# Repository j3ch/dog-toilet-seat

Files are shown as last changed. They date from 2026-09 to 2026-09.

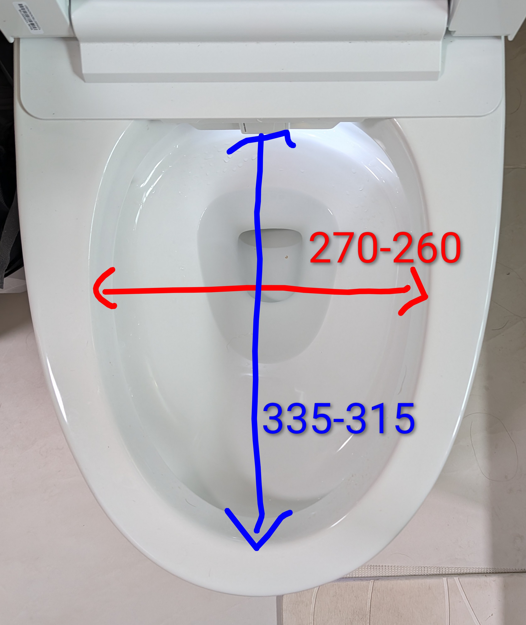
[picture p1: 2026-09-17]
measurements.jpg

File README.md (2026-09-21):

# toiletseat
Design files for a Toilet Seat for Lala for the Kohler Reve for when she gets too old to balance

Lala is getting old and may not be able to balance on the rim for much longer.  These files are for a 3d printed insert to increase the surface area that she can stand on. All four of my toilets are the Kohler Reve, which is square and does not accept standard toiletseats.



Lala primarily balances on the front rim, so that is the area which I intended to make larger.

A piece of clear film was placed over the toilet and it was traced with a marker.



I then replicated the outline in illustrator, and used a cricut to cut the shape from cardstock.  I checked the shape against the toilet, and then made modifications to get as close as I could to the shape. The hole is slightly egg shaped, and the walls tilt inwards at diferent angles.  They are more steep near the corners.

I then used the vector file to extrude the 3d model out in fusion 360 and generally model the object as desired.

It was cut into 4 to facilitate printing on printers will smaller print beds.



I used a phone scanner to scan the toilet into a mesh model which is pretty rough, and looked to see if it matched my model.





The seat was printed in polycarbonate.

InShot_20231030_141507858

Some dimension gaps were noted. 6mm width and 2.5mm height.



It was coated in Gorilla clear spray, and the top was coated with the white plasti dip
It was pretty smooth so it was painted with the black plasti dip with a brush, two coats, then sand was sprinkled all over it
It was then sprayed again with the white plastidip before it really got a chance to dry
InShot_20231030_141906600

InShot_20231030_141920419

Lala was confused by the seat, probably smells strongly of the paint, and it also feels weird and changes how her feet can be positioned. She usually leaves one pad hanging on the inside edge, probably to know where the ledge is. Pretending to go into her crate with food was enough to light a fire under her butt to get her to do what I asked instead of just standing there and alternate looking at the toilet and me.

Typically if she's disinterested in something, if I act like I want it, suddenly she wants it 100x more. The moment I don't want it anymore, she doesn't either. I guess dogs are not all that different than humans.

IMAGE ALT TEXT HERE (https://youtu.be/0RVw_okE6QU)

IMAGE ALT TEXT HERE (https://youtu.be/AzDsTydvyec)

IMAGE ALT TEXT HERE (https://youtu.be/IX3H9Qvbffo)

A new model was made, with ridges and a differently shaped hole.  The geometry of the center flange was also slightly adjusted.



It was printed in PETG this time.

InShot_20231114_142916448

The gaps were filled with waterproof epoxy putty and the entire model was sprayed with the gorilla clear spray. The bottom was then coated in the black plasti dip.  The top was then coated with clear paint on flex seal and sprinkled with fine sand.  As of 12 hours later, it's still tacky, so cure time might be much longer than the plasti dip.

InShot_20231114_142951156

It may take a few days before it's cured enough to coat with the white plasti dip spray.

It took about 30 hours to cure. I then coated it with white spray plasti-dip.

The plasti dip peels freely from the cured flex seal paint on. This could be a feature, or a problem. For now I think it's more of a problem. I think the gorilla + plasti dip paint on + sand + plasti dip spray is a better combo. It also cures faster, but I can't remove the flex seal reasonably, so maybe for next time.

IMAGE ALT TEXT HERE (https://youtu.be/RBduAb9LdPU)

I find the cured flex seal to feel slippery, which is the opposite of what I want, so besides waterproofing it provides no benefit, since all the others also waterproof. It also cures really slow. Unless you want a surface that plasti-dip can peel from for easy replacement, I don't think it's useful.

I peeled off as much of the flex seal as possible and recoated the top with black plasti dip paint on. I then sprinkled it with sand, and coated it with plasti dip white spray. It's very lumpy, since I was unable to get all of the flex seal off, but it has a pretty grippy surface.

Seems fine though, lala doesn't have a problem with it, besides it being a new seat which probably feels a bit different.

IMAGE ALT TEXT HERE (https://youtu.be/_8LVXEE4Dok)

The third print will be a similar model in PC again. This one has 5 connection pegs in the joints and the central flange is a tiny tiny bit bigger.

I plan to glue it with scigrip 16, then coat it in the gorilla clear spray first, then paint the top in plasti-dip clear paint on.  Depending on the grippiness, sand + plasti-dip spray is an option.

The printer I have now has a 200 x 200 mm bed, and the v4 quadrants need up to a
226 mm square, so v4 was re-split into 8 pieces instead of 4:
`toiletv4_sliced_in_8.stl`.

The four original cuts (at X=0 and Z=0, through the middle of each side) are
untouched. Each quadrant gets one new radial cut through its corner, at 45, 135,
225 and 315 degrees. Every piece now fits a 164-180 mm square and is 94.7 mm
tall.

| piece | smallest square bed |
|---|---|
| S0 | 169 mm |
| S1 | 171 mm |
| S2 | 170 mm |
| S3 | 164 mm |
| S4 | 165 mm |
| S5 | 179 mm |
| S6 | 180 mm |
| S7 | 169 mm |

The new joints reuse the v4 connector exactly: 3 round pegs down the skirt
(5 mm peg into a 6 mm hole, 6 mm long, 7 mm deep) and 2 flat tongues in the top
flange (4 x 35 mm tongue into a 5 x 36 mm slot), 0.5 mm clearance per side
throughout. Male and female alternate so every joint has one of each.

One difference worth knowing before printing: the diagonal cuts meet the ~10.5 mm
skirt obliquely, so the bore drifts slightly across the wall as it goes in and
the sockets there are left with 1.1-1.8 mm of wall, against 1.5-2.0 mm on the
original cuts. Still 3+ perimeters, but the skirt pegs on the new corner joints
are the thinnest-walled feature in the part.

The pieces are exported exploded 40 mm outward, the same way the v4 file is laid
out. `tools/split8.py` regenerates the file from `toiletv4_sliced.stl` and
`tools/check8.py` verifies it (watertightness, volume, every connector and its
clearance, bed fit, and that neighbouring pieces mate without interference).
Both need `numpy`, `trimesh`, `manifold3d`, `scipy`, `shapely`.

Note the Fusion `.f3d` files were not updated - the 8-way split was done on the
v4 mesh, so it is STL only.

## Ridges, rebuilt on v4

The ridged redesign only exists here as Fusion `.f3d` archives, and their
geometry is an Autodesk ShapeManager BREP (`ASM BinaryFile4tY`) that nothing
outside Fusion can read - there is no cached mesh in the archive either, so the
shapes cannot be recovered without the kernel that made them.

`toiletv5_rings.svg` is readable though. It is 64 closed curves, each a uniform
outward offset of the hole outline, spaced 7.086 px apart, the innermost sitting
two steps out from the hole. Registering the v4 sketch hole (`toiletcuts_v2.svg`,
617.74 x 690.63 px) against the v4 model's own hole (219.1 x 242.9 mm) gives
0.3532 mm/px, which puts that spacing at 2.503 mm - so the pattern was laid out
on a 2.5 mm offset step.

The v5 hole is a different shape from v4's, so rather than dropping the v5 curves
onto the wrong outline, `tools/ridges.py` rebuilds the same construction on v4's
own hole: concentric outward offsets at 2.5 mm, raised on alternating bands.
### The top is flattened first

v4's top is a shallow dish - it rises about 2.7 mm from the inner edge out to the
rim - so ridges laid on it are not coplanar and a piece will not sit flat on a
bed. `split8.py` fills that dish up to its own high point (y = 14.702) before
anything else, so nothing is cut away and the outer rim keeps its height. The
slab starts at y = 8.6, above the flange slots, and its footprint is read below
them so they do not punch holes in it; it is held 0.25 mm inside the outline,
because flush its wall lands exactly on the part's own wall and that coincident
pair comes apart in the ridge union. A 0.25 mm strip of the original rounded rim
survives at the very edge, and the chamfer at the hole is likewise untouched -
99.87% of the ridged area is flat to within 0.01 mm.

Flattening adds 209 cm3, taking the seat from 2123 to 2333 cm3 before ridges.

Flattening would also square off the rounded lip v4 had where the top meets the
hole - the edge Lala's paws sit against - so a **2 mm 45 degree break** is cut
back along it, as a staircase of 0.2 mm steps that the layer lines round off
anyway. A true quarter-round was tried first and is not usable: its profile ends
in 0.01-0.09 mm offsets from the hole wall, slivers that do not survive STL's
float32 and left one quadrant non-watertight on reload. The break removes
1601 mm3, against 1599 predicted from the 727 mm hole perimeter.

The inset is taken on the assembled seat, so it pulls the slab back from the
outer wall and the hole but not from the cut planes. Applied per quadrant it
also pulled each slab back from its own seams, leaving a 0.5 mm groove down all
four of them. A hairline one (<= 0.2 mm) remains; the bridges cover it
everywhere except the innermost 5 mm.

Ridges are 2.5 mm wide with 2.5 mm flats between them, stand 1.5 mm proud, and
start 5 mm out from the hole. The SVG draws 64 rings, which is 32 bands reaching
162.5 mm - enough for the v5 outline but not for v4, whose back corners are up
to 185 mm from the hole and were left flat for the last 20-23 mm. The band count
is taken from the geometry instead, which comes to 38 here. They are cut from a lifted copy of the part rather
than stamped on at a fixed height, so they follow the sloping top face exactly.
All of that is parameterised at the top of the script.

- `toiletv4_ridged.stl` - the whole seat, 2326.3 cm3, 96.2 mm tall
- `toiletv4_ridged_in_8.stl` - the same thing in the 8 printable pieces

The joints are untouched: the ridge stock is floored at y=8.6 mm, above the
8.5 mm flange slots and below the top face, and each piece's stock is clipped to
its own sector, so no ridge material crosses a cut plane. `tools/check8.py`
passes on the ridged split - all 8 pieces closed shells, every connector still
5/6 mm and 4x35 / 5x36 at 0.5 mm clearance, still 164-180 mm square.

Two things this is not. It is v4 with the v5 ridge pattern, not a reproduction of
the model that was actually printed in PETG - that one also changed the hole
shape and the centre flange, and those changes are locked in the `.f3d`. And
`toiletv4_ridged.stl` is built by reassembling the v4 quadrants, so it keeps the
0.5 mm clearance gap around each of the 20 connectors of the original joints as
internal voids (3.7 cm3). There is no un-sliced v4 in the repo to build it from.

### One file per piece

`pieces/toiletv4_ridged_S0.stl` ... `_S7.stl` are the 8 ridged pieces as separate
solids, ready to open in a slicer: converted to Z up, turned about the vertical
axis to their smallest square footprint, centred on the origin and sitting on
Z=0. `tools/export_pieces.py` regenerates them, and takes any of the split files
as an argument.

| piece | footprint mm | tall mm | volume cm3 |
|---|---|---|---|
| S0 | 166.8 x 168.7 | 79.2 | 237.0 |
| S1 | 171.0 x 169.6 | 79.6 | 289.7 |
| S2 | 170.0 x 170.6 | 79.6 | 291.3 |
| S3 | 162.1 x 163.6 | 79.2 | 219.1 |
| S4 | 165.5 x 164.6 | 79.3 | 255.3 |
| S5 | 179.6 x 178.7 | 79.6 | 327.2 |
| S6 | 179.1 x 180.5 | 79.6 | 327.8 |
| S7 | 168.7 x 169.1 | 79.3 | 258.0 |

They are exported **turned over**: ridged face down, skirt pointing up. Printed
the other way up the flange cantilevers 80 mm out above the thin bottom edge of
the skirt and wants support under all of it; this way there is nothing to
support. The turn is a 180 degree rotation, never a mirror - `export_pieces.py`
asserts the placement matrix has determinant +1, because mirroring would reverse
every peg and socket. Pass `--upright` for the other orientation.

`export_pieces.py` also levels each piece onto its best resting plane, scoring
candidate hull facets by what actually touches the bed rather than by how much
area faces it. Now that the top is flat this comes out at **0.00 degrees** - the
pieces already sit flat. `--no-level` skips it, `--upright` turns them back over.

### Bridges across the ridges

A flat top is not enough on its own. The first print still lifted, and the
first-layer footprint shows why: the concentric bands land on the bed as about
25 unconnected ribbons, 2.5 mm wide and up to 250 mm long, with nothing joining
them until 1.5 mm up. Each ribbon is free to curl at its ends. Nothing was out
of plane - all 13294 mm2 of ridge top sat at exactly z=0 - so trimming ridge
height would not have helped; it would have left the same 25 ribbons.

A 10 mm radial bar at each cut plane crosses every band and ties them into one
network, and sits on a seam rather than in the middle of a face. Bars go at all
eight seam angles, not just the four 4-piece borders: the outermost bands exist
only in the corners and never reach a 4-piece border, so with four bars
12373 mm2 was still loose in 56 pieces.

Closing it off is a plain **10 mm border** right round the outer edge, no ridges
in it, which catches the outer end of every arc and encloses the pattern. With
the bars and the border together, **every piece's first layer is a single
connected region - 100%, all twelve of them**, quadrants and eighths alike.
Contact is **17083-20265 mm2** on the quadrants and 7680-11289 mm2 on the
eighths, against 13294-15850 and 3547-5854 before any of this.

Bands on one side, bars and border on the other, extruded apart and merged as
solids. Merged in 2D first they make one polygon with 1200+ points and 56
holes, which the triangulator cannot close. The bars and border do have to be
unioned with each other first, since the spokes run into the ring.

## Fitting the measured bowl

`measurements.jpg` has the opening measured on the toilet: **335 mm** on the long
axis and **270 mm** across at the rim, tapering inward to **315 x 260** over the
first 60 mm of depth. The skirt may go no more than 70 mm into the bowl.

### Skirt shortened to 65.4 mm

v4's skirt is 80 mm. It cannot simply be cut at 70 mm, because the lowest
connector is not at the same height on every original mating face - the four
lowest sockets top out at −68.0, −67.0, −67.0 and −65.905 mm - and a cut at −70
bisects three of them. The deepest cut that leaves every joint feature whole is
0.5 mm above the highest, so `SKIRT_TRIM_Y = -65.4`, giving a **65.4 mm** skirt.
That is under the 70 mm limit with room to spare.

The four original joints lose their lowest peg to the trim and now carry 2 pegs
+ 2 tongues. The four new diagonal joints still carry 3 pegs + 2 tongues, placed
by `split8.py` at whatever heights leave the most wall - it now searches within
6 mm of each nominal height rather than using fixed ones, because the skirt
thins and drifts differently around the ring. Wall left around the new sockets is
1.22-1.69 mm, against v4's own 1.5-2.0 mm.

Overall the seat is now 375 x 427 mm in plan and 81.6 mm tall, pieces
164-180 mm square and 81.1-81.6 mm tall.

### Does it drop in?

Yes, with 4.5-9.5 mm a side everywhere. `skirt_vs_bowl.png` overlays the skirt on
the measured opening. Comparing extreme dimensions at each depth:

| depth | skirt W x L | opening W x L | clearance per side |
|---|---|---|---|
| 1 mm | 255.9 x 319.9 | 269.8 x 334.7 | +7.0 / +7.4 |
| 10 mm | 251.8 x 315.8 | 268.3 x 331.7 | +8.3 / +7.9 |
| 20 mm | 249.5 x 313.7 | 266.7 x 328.3 | +8.6 / +7.3 |
| 40 mm | 245.2 x 309.5 | 263.3 x 321.7 | +9.1 / +6.1 |
| 60 mm | 241.1 x 305.3 | 260.0 x 315.0 | +9.4 / +4.9 |
| 65.4 mm | 240.0 x 304.1 | 259.1 x 313.2 | +9.5 / +4.5 |

The tightest point is +4.5 mm a side, at the bottom of the skirt on the long
axis. Nothing interferes at any depth.

One caveat, as ever: these are extreme dimensions, not shapes, and two outlines
with compatible bounding boxes need not nest. Tested against a true ellipse of
the stated axes the skirt is still slightly proud - 0.2 to 2.6 mm, worst at the
rim, at one end of the long axis, where the traced shape is squarer than an
ellipse. Real bowls are fuller than ellipses, which is presumably why it was
traced that way, and a couple of millimetres is inside the tolerance of a tape
measure on porcelain. Tracing the opening on film, as the original was, would
settle it outright.

### Four pieces, on v4's own cuts

`4pieces/toiletv4_ridged_Q0.stl` ... `_Q3.stl` are the ridged seat split the way
v4 originally was - the planes X=0 and Z=0, carrying v4's own connectors, no new
joints made. The quadrants already are that split, so they only needed the
ridges adding, each clipped to its own 90 degree sector so no ridge material
crosses a cut plane. Volumes sum to 2208.8 cm3 against the whole seat's 2208.9,
which is the check that nothing was added or removed.

| piece | footprint mm | tall mm | volume cm3 | smallest square bed |
|---|---|---|---|---|
| Q0 | 197.7 x 226.6 | 80.2 | 527.8 | 226 mm |
| Q1 | 187.6 x 220.8 | 80.3 | 511.5 | 220 mm |
| Q2 | 192.5 x 214.3 | 80.3 | 583.6 | 213 mm |
| Q3 | 191.0 x 208.6 | 80.3 | 586.9 | 207 mm |

**These do not fit a 200 mm bed** - they need 207 to 226 mm square, which is the
reason the seat was re-split into 8 in the first place. The 8-piece set in
`pieces/` (164-180 mm square) is still there. Everything else about the four
pieces is sound: each is a single closed shell, every edge used twice, and each
joint reads back as 2 pegs + 2 tongues at 0.5 mm clearance.

`tools/check8.py` works on either split - it takes the piece count from the file.

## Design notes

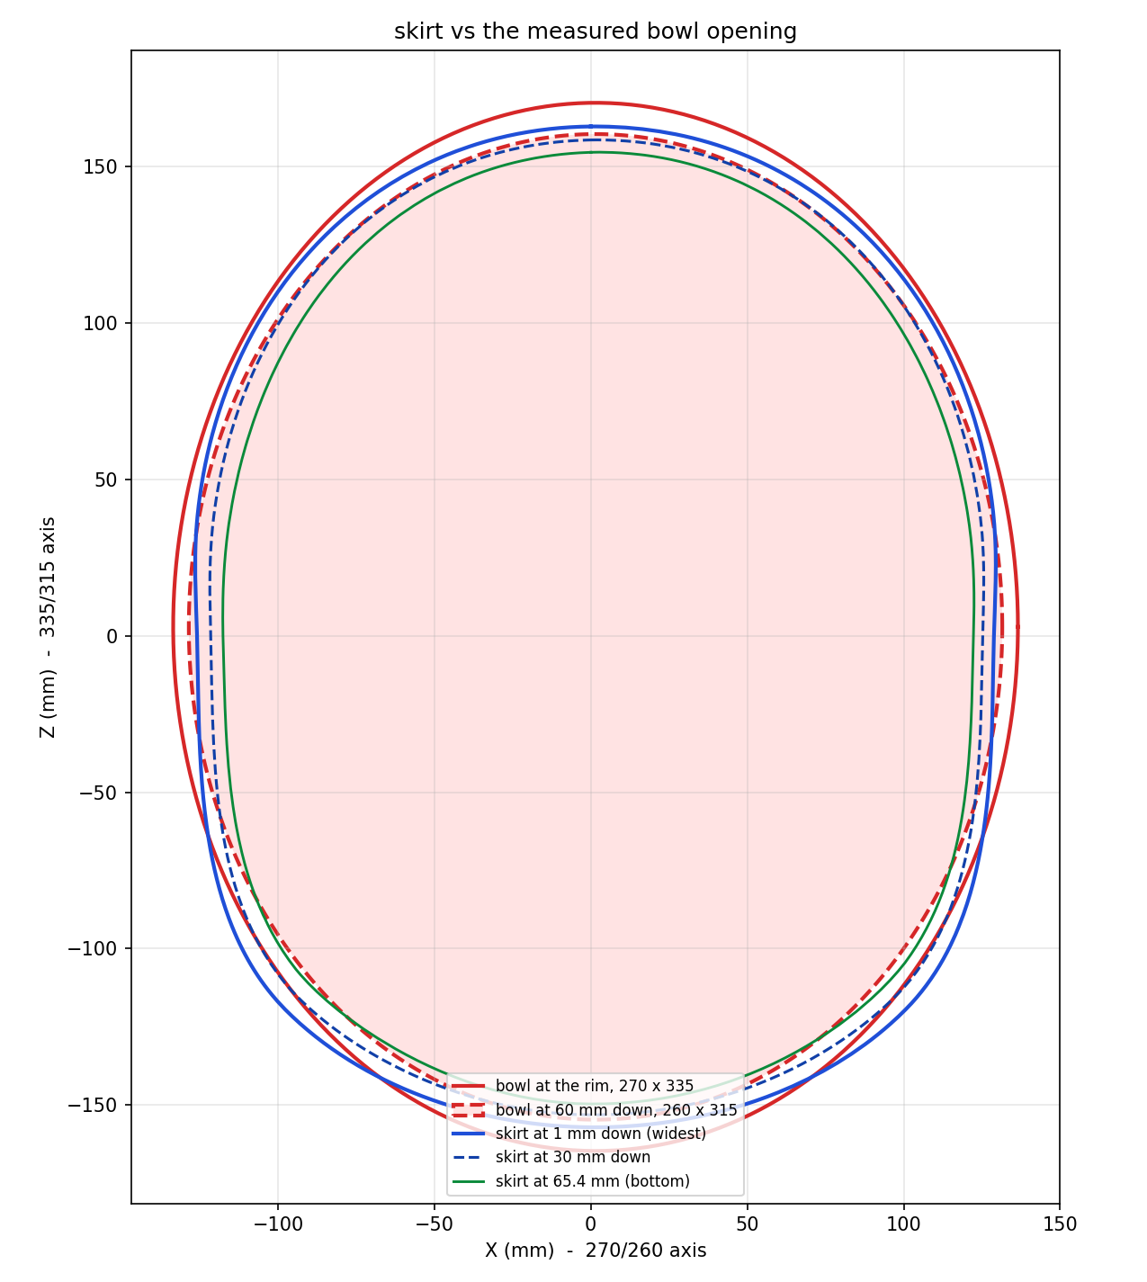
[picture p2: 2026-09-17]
skirt_vs_bowl.png

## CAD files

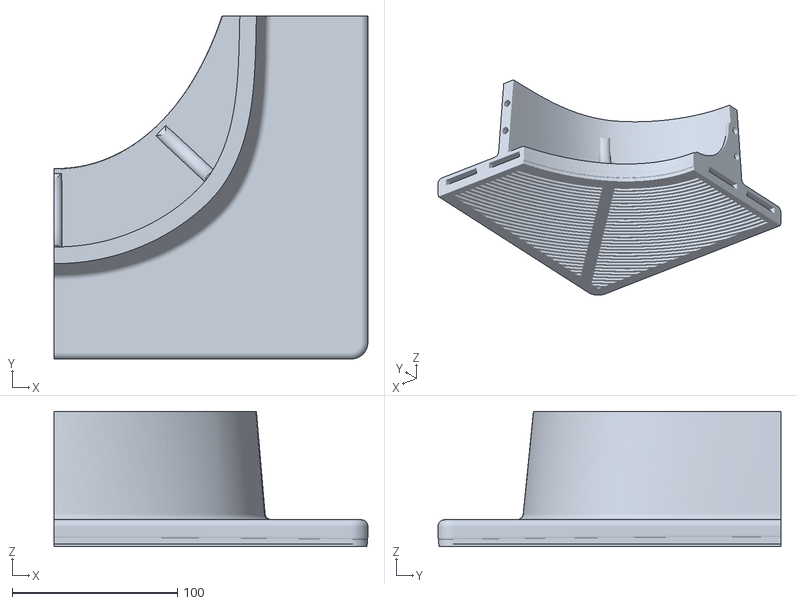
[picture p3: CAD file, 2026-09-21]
4pieces/toiletv4_ridged_Q3.stl
189.6 x 207.3 x 81.6

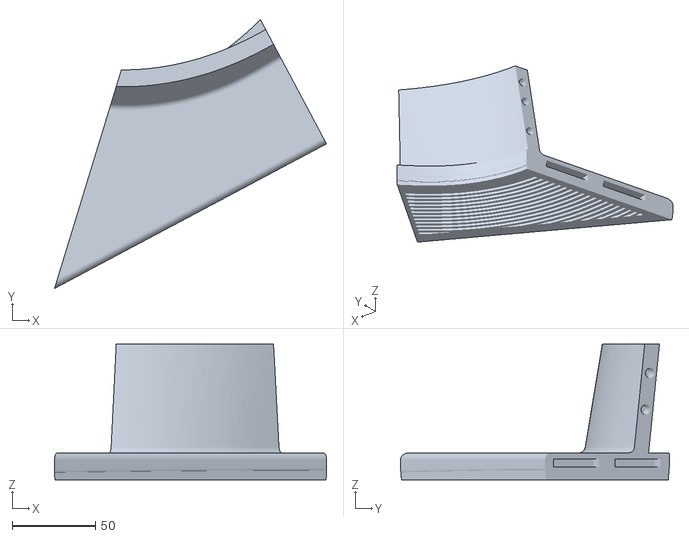
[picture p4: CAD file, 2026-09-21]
pieces/toiletv4_ridged_S3.stl
163.7 x 161.9 x 81.6

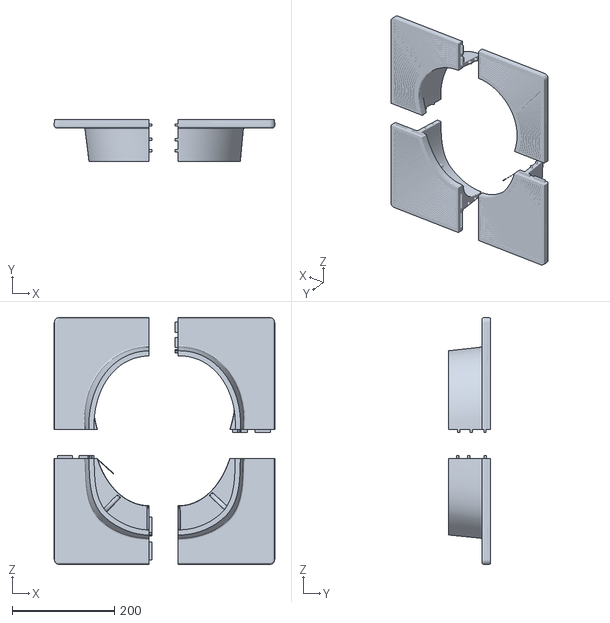
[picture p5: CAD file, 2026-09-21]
toiletv4_ridged_in_4.stl
431.6 x 81.6 x 483.4

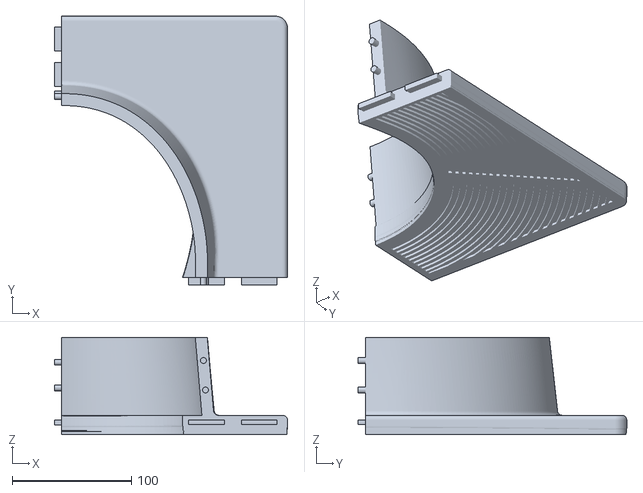
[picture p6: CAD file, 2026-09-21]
4pieces/toiletv4_ridged_Q0.stl
195.6 x 225.5 x 81.6

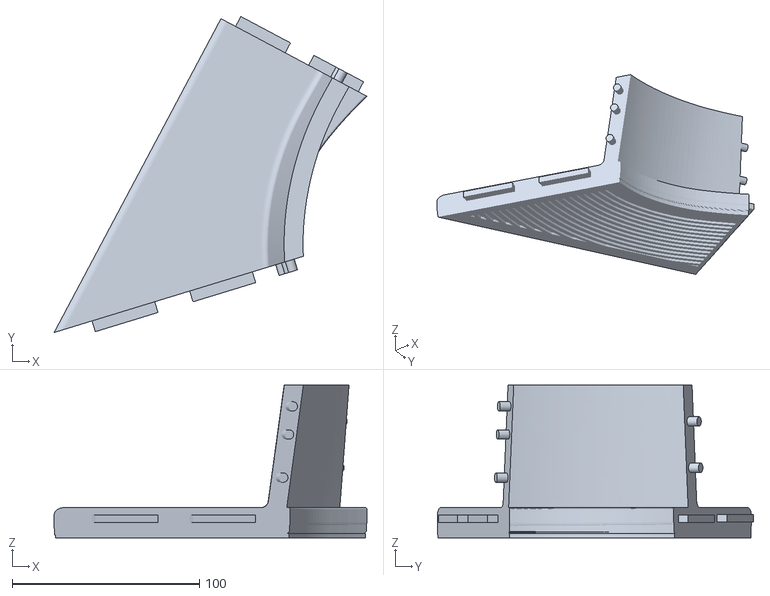
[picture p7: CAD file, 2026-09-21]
pieces/toiletv4_ridged_S0.stl
166.9 x 168.6 x 81.6

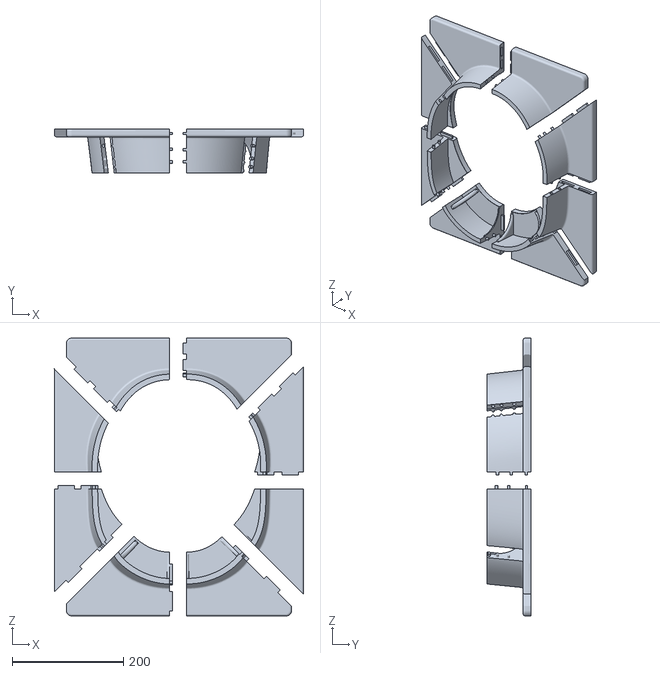
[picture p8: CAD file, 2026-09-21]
toiletv4_sliced_in_8.stl
448.9 x 80.1 x 500.7

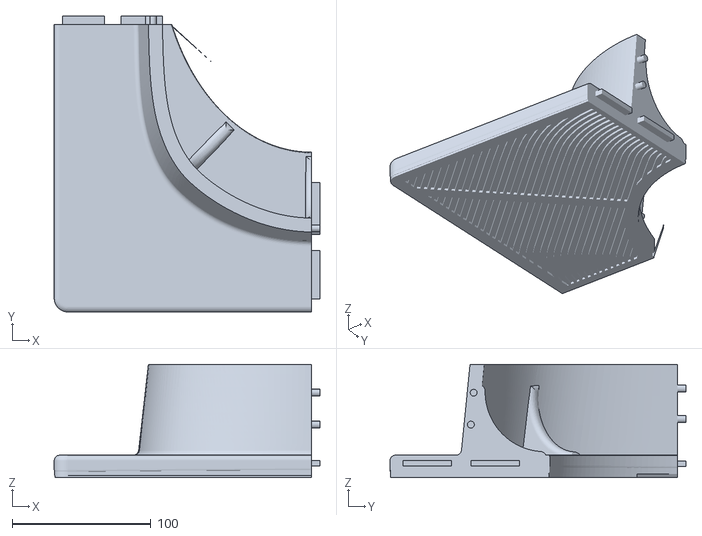
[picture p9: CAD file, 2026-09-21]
4pieces/toiletv4_ridged_Q2.stl
191.4 x 213.3 x 81.6

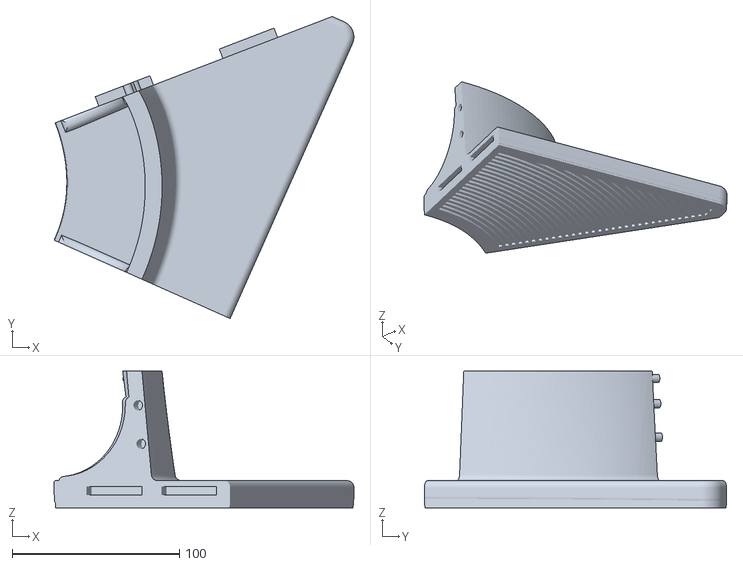
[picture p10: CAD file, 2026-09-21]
pieces/toiletv4_ridged_S6.stl
179.1 x 180.4 x 81.6

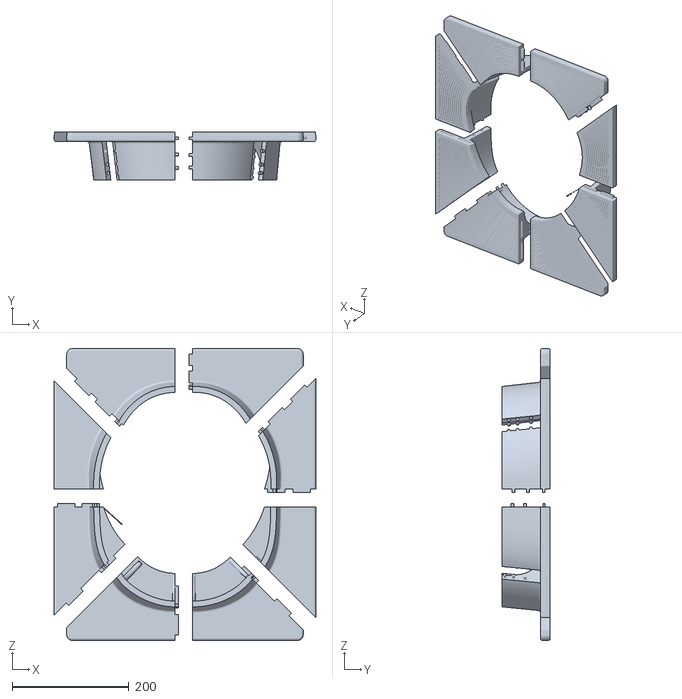
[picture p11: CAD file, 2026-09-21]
toiletv4_ridged_in_8.stl
448.9 x 81.6 x 500.7

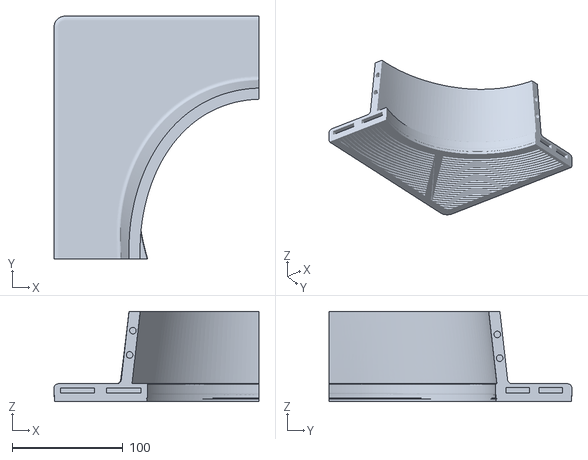
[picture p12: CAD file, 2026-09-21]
4pieces/toiletv4_ridged_Q1.stl
185.4 x 219.5 x 81.6

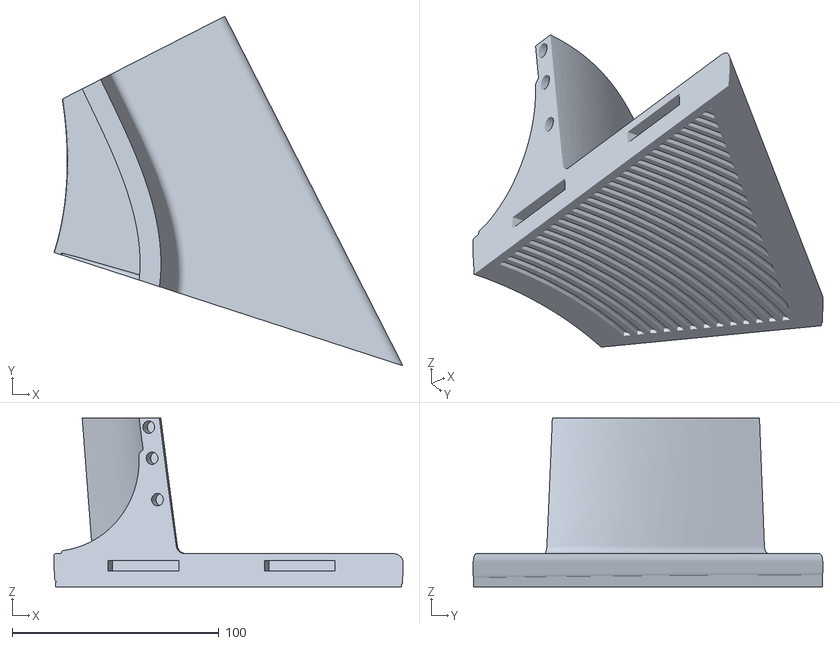
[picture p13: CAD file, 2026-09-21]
pieces/toiletv4_ridged_S7.stl
168.7 x 169.0 x 81.6

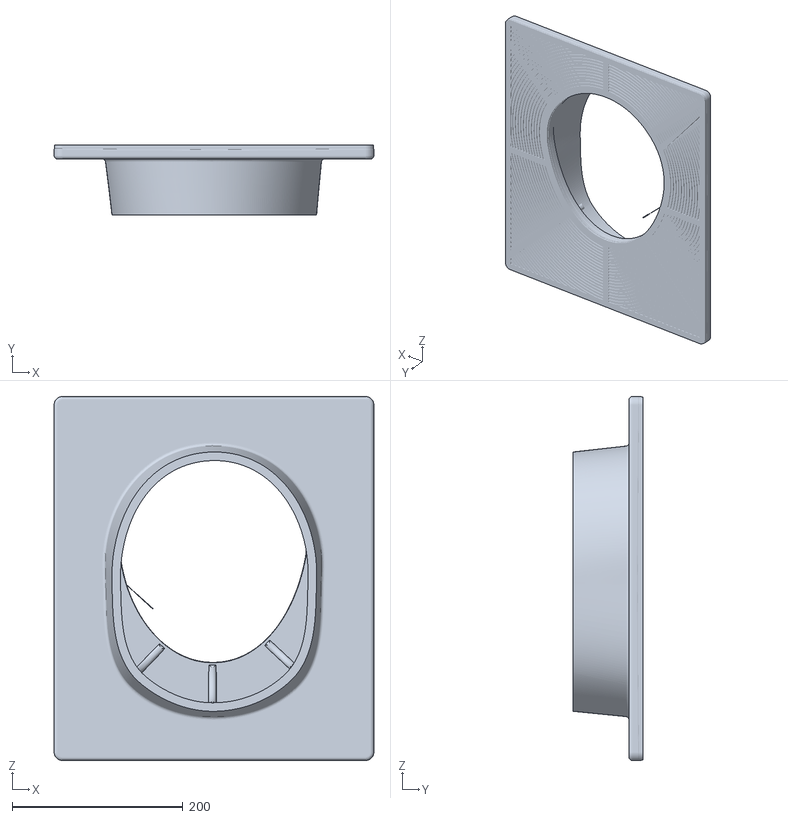
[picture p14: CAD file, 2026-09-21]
toiletv4_ridged.stl
375.0 x 81.6 x 426.8

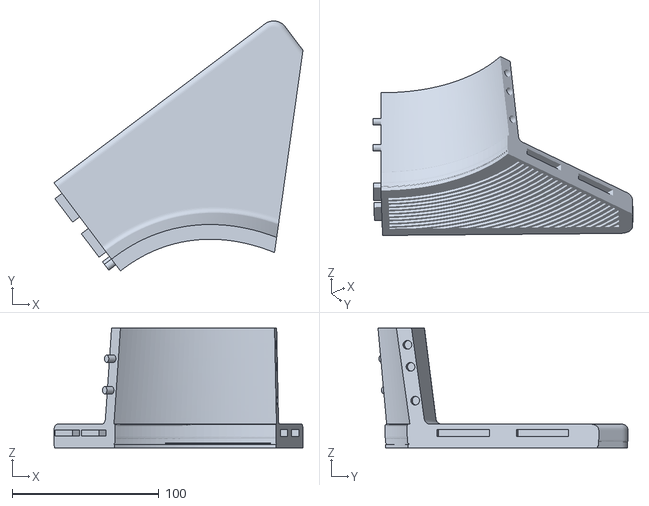
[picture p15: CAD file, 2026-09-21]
pieces/toiletv4_ridged_S1.stl
169.4 x 170.1 x 81.6

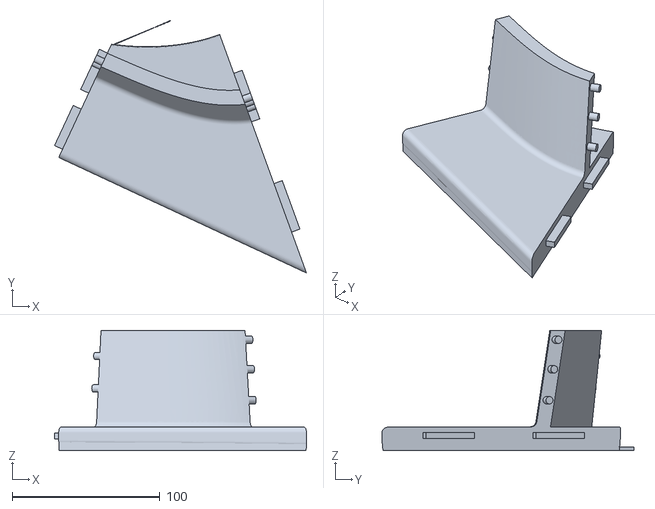
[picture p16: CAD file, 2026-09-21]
pieces/toiletv4_ridged_S4.stl
170.8 x 170.9 x 81.6

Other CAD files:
pieces/toiletv4_ridged_S5.stl
pieces/toiletv4_ridged_S2.stl

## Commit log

2026-09-16 Split v4 into 8 pieces to fit a 200 mm bed
    The v4 quadrants need up to a 226 mm square, which no longer fits. Add one
    radial cut through each quadrant's corner, at 45/135/225/315 degrees, leaving
    the four original cuts at X=0 and Z=0 untouched. Every piece now fits a
    164-180 mm square and is 94.7 mm tall.
    The new joints reuse the v4 connector exactly: 3 round pegs down the skirt
    (5 mm peg into a 6 mm hole) and 2 flat tongues in the flange (4x35 into 5x36),
    0.5 mm clearance per side, male and female alternating so every joint has one
    of each. Connector positions are measured from the cross-section at each cut
    rather than hard-coded, so each peg stays centred in its wall as the wall
    curves aw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
    [toiletv4_sliced_in_8.stl]
2026-09-16 Rebuild the ridged version on v4 geometry
    The ridged redesign is only in the .f3d archives, whose geometry is an Autodesk
    ShapeManager BREP with no cached tessellation, so it cannot be read outside
    Fusion. toiletv5_rings.svg can be read: 64 closed curves, each a uniform outward
    offset of the hole outline at 7.086 px, innermost two steps out.
    Registering the v4 sketch hole (toiletcuts_v2.svg, 617.74 x 690.63 px) against
    the v4 model's hole (219.1 x 242.9 mm) gives 0.3532 mm/px, putting that spacing
    at 2.503 mm - the pattern was laid out on a 2.5 mm offset step. The v5 hole is a
    different shape from v4's, so ridges.py rebuilds the construction on v4's own
    hole instead of mapping the v5 curves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
    [toiletv4_ridged.stl, toiletv4_ridged_in_8.stl]
2026-09-17 Export each ridged piece as its own STL
    The split files hold all 8 pieces in one mesh, in assembled-and-exploded
    positions with Y up, which a slicer reads as one object lying on its side.
    pieces/toiletv4_ridged_S0.stl ... _S7.stl are the same 8 solids one per file,
    converted to Z up, turned about the vertical axis to their smallest square
    footprint, centred on the origin and dropped onto Z=0.
    Each file verified independently of trimesh: single shell, every edge used
    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
    [toiletv4_ridged_S0.stl, toiletv4_ridged_S1.stl, toiletv4_ridged_S2.stl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]
2026-09-17 Trim the skirt to fit the measured bowl
    measurements.jpg gives the opening: 335 x 270 mm at the rim, tapering to
    315 x 260 about 10 mm down, with at most 70 mm of skirt allowed. v4's skirt is
    80 mm.
    It cannot just be cut at 70 mm. The lowest connector is at a different height on
    each original mating face - the four lowest sockets top out at -68.0, -67.0,
    -67.0 and -65.905 - so a cut at -70 bisects three of them, leaving half-pegs and
    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
    [toiletv4_ridged.stl, toiletv4_ridged_S0.stl, toiletv4_ridged_S1.stl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]
2026-09-17 Correct the bowl taper: 10 mm over 60 mm of depth
    I had read "tapers down 1cm" as the taper completing within 10 mm of the rim.
    It is 335 x 270 at the rim narrowing to 315 x 260 over the bowl's first 60 mm,
    so the opening is wider than assumed at every depth but the last.
    That removes the only interference. The skirt now clears by 4.5-9.5 mm a side
    everywhere, tightest at the bottom of the skirt on the long axis, instead of
    being 0.4 mm proud at 10 mm down. Against a true ellipse of the stated axes it
    is proud by 0.2-2.6 mm rather than 8.6 mm, small enough to sit inside both the
    tracing tolerance and the gap between an ellipse and a real bowl.
    No geometry change - the 65.4 mm skirt and the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
2026-09-20 Also split the ridged seat into 4 on v4's original cuts
    4pieces/toiletv4_ridged_Q0.stl ... _Q3.stl: the ridged seat cut the way v4 was,
    on X=0 and Z=0 with v4's own connectors. No new joints are made - the quadrants
    already are that split, so they only need the ridges adding, each clipped to its
    own 90 degree sector so no ridge material crosses a cut plane. The four volumes
    sum to 2208.8 cm3 against the whole seat's 2208.9, which is the check that the
    split neither adds nor removes anything.
    Each piece is a single closed shell with every edge used twice, and each joint
    reads back as 2 pegs + 2 tongues at 0.5 mm clearance.
    They do not fit a 200 mm bed: 207-226 mm square, which is why the se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
    [toiletv4_ridged_Q0.stl, toiletv4_ridged_Q1.stl, toiletv4_ridged_Q2.stl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]
2026-09-20 Export the pieces turned over, ridged face down
    Printed skirt-down the flange cantilevers 80 mm out above the thin bottom edge
    of the skirt and needs support under all of it. Turned over, the skirt points up
    and nothing needs support.
    The turn is a 180 degree rotation, not a mirror: export_pieces.py now asserts
    the placement matrix has determinant +1 and that the volume is unchanged, since
    mirroring would reverse every peg and socket and the pieces would no longer
    mate. --upright restores the old orientation.
    The ridged face does not quite lie flat - it is 0.5-1.3 degrees off parallel,
    which over a 170 mm piece is up to 3 mm against 1.5 mm ridges, so first-layer
    contact is 46-376 mm2 of ri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
    [toiletv4_ridged_Q0.stl, toiletv4_ridged_Q1.stl, toiletv4_ridged_Q2.stl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]
2026-09-20 Level each piece onto the bed instead of leaving it a degree proud
    Turned over, the ridged face points at the bed but sits about a degree off
    parallel - over a 170 mm piece that lifts one end clear of the 1.5 mm ridges, so
    only 46-376 mm2 was touching.
    export_pieces.py now shortlists the convex hull facets that point at the bed,
    lays each flat in turn, and keeps whichever actually puts the most material
    down. Scoring on real contact rather than on how much mesh area faces that way
    matters: the naive score left S6 resting on 1072 mm2 because a face can present
    plenty of area and still meet the bed along one edge.
    First-layer contact on the eight pieces goes from 46-376 mm2 to 3547-5854 mm2,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
    [toiletv4_ridged_Q0.stl, toiletv4_ridged_Q1.stl, toiletv4_ridged_Q2.stl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]
2026-09-20 Run the ridges out to every corner, not just 32 bands' worth
    The SVG draws 64 rings - 32 bands, reaching 162.5 mm from the hole. That covers
    the v5 outline, but v4's hole sits toward the front, so its back corners are
    183-185 mm out and the last 20-23 mm of Q2 and Q3 was left flat.
    The count now comes from the geometry: the furthest point of the flange from the
    hole, rounded up to a whole band, which is 38 here and reaches 192.5 mm. Q0 and
    Q1 were already covered and are byte-identical; Q2 and Q3 gain 0.4 and 0.5 cm3
    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
    [toiletv4_ridged.stl, toiletv4_ridged_Q0.stl, toiletv4_ridged_Q1.stl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]
2026-09-20 Flatten the seat's top, then re-split
    v4's top is a shallow dish rising ~2.7 mm from the inner edge to the rim, so
    ridges laid on it are not coplanar and no piece sits flat on a bed. split8.py
    now fills that dish up to its own high point (y = 14.702) before anything else,
    so nothing is cut away and the rim keeps its height. 99.87% of the ridged area
    is flat to within 0.01 mm; the rest is the chamfer at the hole. Flattening adds
    209 cm3, 2123 -> 2333 before ridges.
    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
    [toiletv4_ridged.stl, toiletv4_ridged_Q0.stl, toiletv4_ridged_Q1.stl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]
2026-09-21 Bridge the ridges so the first layer is one connected network
    The first print lifted even though the ridge tops were exactly coplanar - all
    13294 mm2 of them sat at z=0, with nothing between 0.01 and 0.5 mm, so no ridge
    was short or proud. The first-layer footprint shows the real problem: about 25
    unconnected concentric ribbons, 2.5 mm wide and up to 250 mm long, joined to
    nothing until 1.5 mm up, each free to curl at its ends. Trimming ridge height
    would not have changed that - same 25 ribbons, same contact.
    A 10 mm radial bar at each cut plane crosses every band and ties them together,
    and falls on a seam rather than in the middle of a face.
    Bars go at all eight seam angles rather than t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
    [toiletv4_ridged.stl, toiletv4_ridged_Q0.stl, toiletv4_ridged_Q1.stl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]
2026-09-21 Border round the outer edge, closing the pattern into one region
    A plain 10 mm band round the outer edge of the top, no ridges in it, catching
    the outer end of every arc and enclosing the pattern.
    With the bars and the border together every piece's first layer is now a single
    connected region - 100% on all twelve, quadrants and eighths alike. The bridges
    alone left Q0 at 98% in 6 regions and two of the smaller pieces at 64-67%.
    Bed contact is 17083-20265 mm2 on the quadrants and 7680-11289 mm2 on the
    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
    [toiletv4_ridged.stl, toiletv4_ridged_Q0.stl, toiletv4_ridged_Q1.stl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]
2026-09-21 Break the hole edge back, and stop the inset cutting the seams
    Flattening squared off the rounded lip where the top meets the hole, which is
    the edge Lala's paws sit against. A 2 mm 45 degree break is now cut along it,
    as a staircase of 0.2 mm steps - finer than a layer, so the printed edge rounds
    itself. Verified by volume: 1601 mm3 removed against 1599 predicted from the
    727 mm hole perimeter and a 2.20 mm2 staircase section.
    A true quarter-round was tried first and is not usable. Its profile ends in
    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
    [toiletv4_ridged.stl, toiletv4_ridged_Q0.stl, toiletv4_ridged_Q1.stl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]
